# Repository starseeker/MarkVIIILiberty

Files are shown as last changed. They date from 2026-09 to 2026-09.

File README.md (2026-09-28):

# Mark VIII Liberty Tank

This repository is a research and reconstruction project devoted to the First World War–era **Mark VIII tank**, commonly called the **Liberty tank** or **International tank**. It is intended to hold historical notes, transcriptions, photographs, drawings, dimensional evidence, and—eventually—CAD models of the vehicle and its components.

The goal is not merely to produce a visually convincing model. Wherever possible, the project will record the source behind each feature, distinguish documented dimensions from estimates, and preserve uncertainty where the surviving evidence does not support a single answer.

Current state:

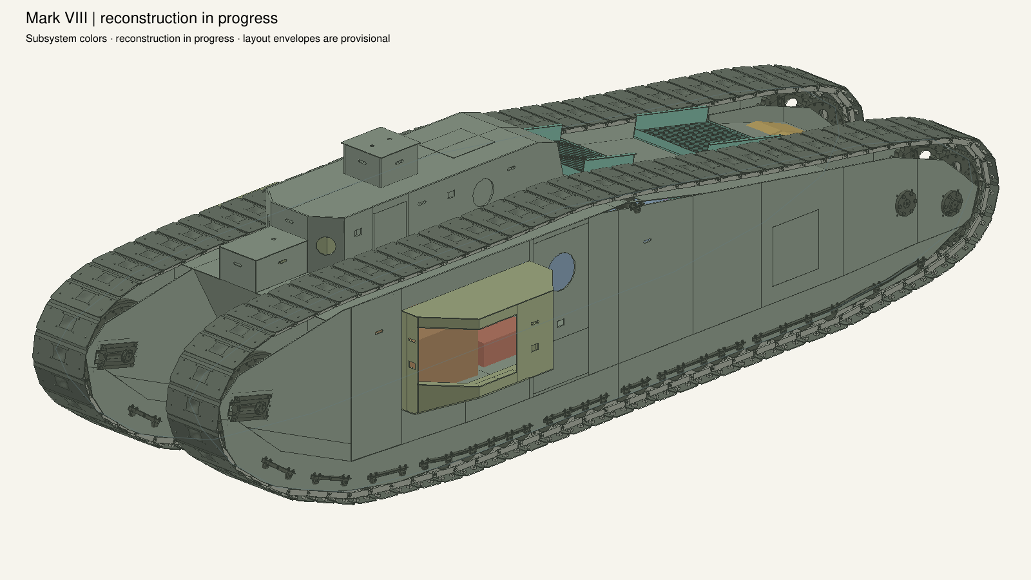
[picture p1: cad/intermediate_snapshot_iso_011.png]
MarkVIII_exterior

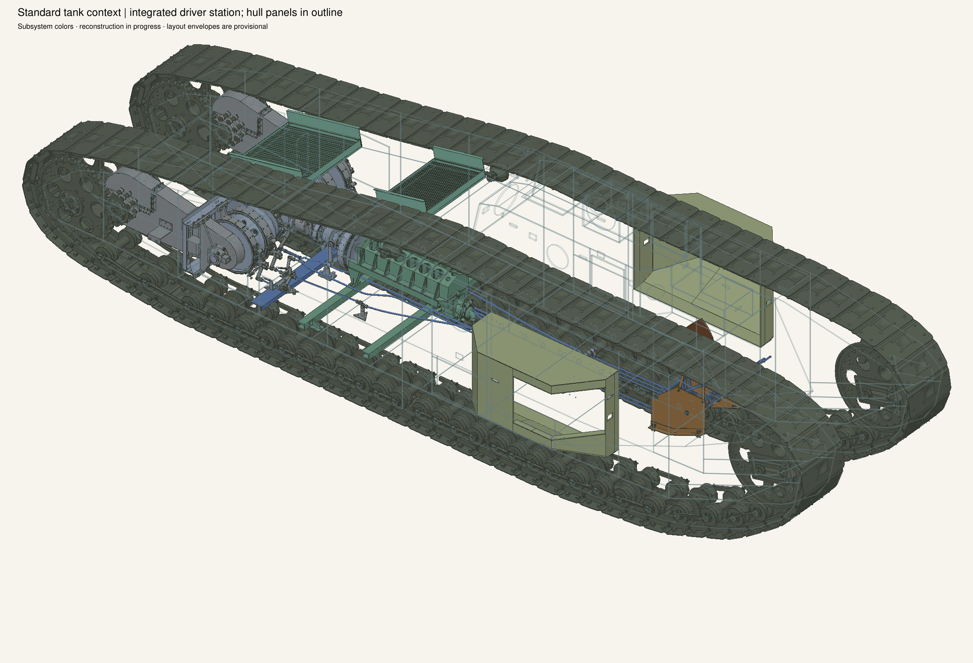
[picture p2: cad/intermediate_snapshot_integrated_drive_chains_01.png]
MarkVIII_interior


## What the Mark VIII was

The Mark VIII was a late-World War I heavy tank designed through a joint British-American program, with France also involved in the intended manufacturing arrangement. The design was meant for the anticipated 1919 Allied offensive and represented an attempt to combine British experience with American industrial capacity. Its collaborative origin is why it is often called the **International** tank.

The American version was powered by a 300-horsepower Liberty L-12 engine, which gave rise to the name **Liberty tank**. It was a large, slow, trench-crossing vehicle with a long hull, substantial track runs, and a separate engine compartment—an important improvement over the cramped engine-and-crew arrangements of earlier British heavy tanks. Its principal armament consisted of two 6-pounder guns mounted in side sponsons, supported by multiple machine guns.

The Armistice came before the tank could enter combat. After the war, the United States assembled 100 Mark VIII tanks at Rock Island Arsenal during 1919–1920 using British-made armor and other components. They served primarily as training vehicles with the U.S. Tank Corps and later the Infantry Branch until their retirement in 1932. British production and prototype counts are reported somewhat differently depending on whether a source is counting national variants, prototypes, or completed vehicles; this repository will preserve those distinctions rather than silently collapsing them into one number.

Only three Mark VIII tanks are generally reported to survive: one British-built example at [The Tank Museum](https://tankmuseum.org/tank_collection/mark-viii?country=all&era=all&tname=&tpage=), and two American examples in U.S. Army collections, including the restored vehicle at [Rock Island Arsenal](https://www.aschq.army.mil/About/History/Tours/RIA/Ordnance/) and the example described by the U.S. Army’s [Mark VIII historical article](https://www.lineofdeparture.army.mil/Journals/Army-History/Archive/Summer-2024-Issue/MarkVIII/). Contemporary testing is also documented in the Imperial War Museums’ film record, [“Trials of the Mark VIII ‘Liberty’ tank”](https://film.iwmcollections.org.uk/record/4178).

## Research and modeling scope

The project may include:

- historical background and terminology;
- source and archive references;
- scans, photographs, and extracted technical drawings;
- transcribed dimensions and dimensional comparisons;
- notes on American and British production differences;
- FreeCAD or other open CAD source files;
- scripts for image preparation, measurement, and model generation; and
- rendered views and documentation of the completed models.

The intended modeling standard is **evidence-led reconstruction**. A part may be modeled as confirmed, probable, inferred, or purely illustrative, with the status recorded in the accompanying documentation. When multiple surviving tanks or drawings differ, the model should identify which configuration it represents instead of presenting one vehicle as universally definitive.

The current source strategy separates the intended 1918 design, later American production and service practice, component-specific documentation, and modern observation. The [primary-source index](docs/primary-sources.md) now includes the 1920 Rock Island Arsenal production account, contemporary Ordnance technical articles, official 1920 reports, a participant's account of the International-tank program, Alden's sponson patent, and period test films. The [modern-reference index](docs/modern-reference-sources.md) remains separate so that observations of surviving museum vehicles are not confused with period design evidence.

The adopted first CAD baseline is the 1919–1920 American Rock Island first-100 production tank. The 1918 prototype or British/International configuration and later service states represented by the 1928 SNL may differ in fittings, equipment, and details. Those differences should be represented as documented variants rather than silently merged.

## Possible repository layout

The structure will evolve as the project develops, but a likely arrangement is:

```text
docs/          historical notes, source summaries, and research log
references/    photographs, drawings, dimensional references, and indexes
cad/           FreeCAD documents and other native model files
exports/       selected meshes, technical illustrations, and renderings
scripts/       processing and model-generation utilities
```

Large or externally hosted source files may be represented by metadata, checksums, accession information, and links rather than committed directly. Copyright, archive terms, and provenance should be recorded whenever material is added.

## Historical references

- [Primary sources and modeling hierarchy](docs/primary-sources.md)
- [Modern observational sources](docs/modern-reference-sources.md)
- [The Mark VIII Tank — U.S. Army, *Army History*](https://www.lineofdeparture.army.mil/Journals/Army-History/Archive/Summer-2024-Issue/MarkVIII/)
- [Mark VIII Tank — Rock Island Arsenal](https://www.aschq.army.mil/About/History/Tours/RIA/Ordnance/)
- [Mark VIII — The Tank Museum](https://tankmuseum.org/tank_collection/mark-viii?country=all&era=all&tname=&tpage=)
- [Tank Mark VIII — Imperial War Museums film collection](https://film.iwmcollections.org.uk/record/4178)

## Status

The [CAD foundation and pilot](cad/002_Foundation/README.md) provides a scripted
FreeCAD build of representative track, roller, and structural-joint parts in a
hierarchical assembly, with a simplified vehicle reference blockout. It includes
source-linked parameters, calibration records, STEP exports, and validation.
The [source survey](cad/001_Survey/survey_report.md) remains the frozen research
baseline. Geometry with incomplete historical evidence is explicitly provisional;
the pilot is not a complete or manufacturing-ready tank model.

The [complete-tank workflow](docs/complete-tank-workflow.md) defines the path from
that pilot through production inventory, full-vehicle layout, exterior and
interior reconstruction, and a validated native assembly release. Its
[execution queue](cad/003_FullTank/README.md) records the work packets and
dependencies. Full-tank implementation now includes a production-triage inventory,
an initial native installation layout, seven track component definitions in two
closed 78-unit tracks, 26 individual upper enclosure plates and closed leaves,
77 main hull plates, 39 sponson plates, 82 roof-louver components, 1,228 components
in 60 lower/upper roller stacks with four upper support angles, 306 front-idler
wheel/shaft/adjustment components, 34 lower support angles with 76 attachment
bolts, 298 driving-wheel/shaft/bearing components, 196 partial roller-pinion
components, and source/model comparison views. The
upper enclosures, hull and sponsons now have hollow interiors, with separate
floors, sides, roof pieces and closed standard leaves. Remaining hull structures,
sponson shields/supports, lower support retention, upper attachment/covers,
exact drive/pinion bearing profiles, chain drive and remaining idler attachment details,
louver spacing/support hardware, fittings and interiors still need population. The
[visual progression](cad/VISUAL_PROGRESSION.md) preserves milestone isometrics,
including a transparent-hull view from milestone011 onward. The isolated
[transmission bevel-drive candidate](cad/003_FullTank/packets/I03-bevel-drive.md)
now contains 1,199 parts, including bevel gears, clutch and thrust-bearing
internals; standard-tank integration is pending.
Track closure uses the
printed pin pitch; wheel engagement remains unresolved. The complete tank and
interior reconstruction remain in progress. Standard assembled geometry takes
priority; selected static poses follow after that population work.

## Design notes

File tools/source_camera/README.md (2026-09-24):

# Reusable source cameras

Each source image has an explicit projection hypothesis, fitting landmarks,
independent held-out landmarks and an immutable numerical fit. New geometry is
normally viewed through the existing camera. A lower residual alone does not
justify changing it or changing the CAD model.

The fitter supports perspective (square pixels, no lens distortion), orthographic
(including rotated axonometric views) and explicitly selected oblique/affine
illustrations. Affine projection is not a physical perspective camera. Mixed
views, exploded arrangements and local drawing distortions may have no single
valid camera. Classify these instead of increasing model flexibility until they fit.

## Reuse and refit policy

| Change | Action |
|---|---|
| New unrelated parts, detail, color or visibility | Reuse camera; render current geometry |
| New held-out landmarks | Reuse camera; recompute residuals |
| Holdouts conflict | Flag review; inspect picks, projection and geometry independently |
| Fitting anchor placement changes | Recompute coordinates; review refit reason; retain old fit |
| Anchor definition changes | Stop and reverify the local locator against the revised shape |
| Source pixels/crop/rotation change | Reverify image picks; use a new image hash |
| Projection, assumptions or solver changes | Separate fit version and before/after review |

Numerical fits are usually inexpensive on small landmark sets. Source reading,
landmark identification and diagnosis are the costly reasoning steps worth
preserving. Cache identity includes original image bytes and dimensions, projection,
fit coordinates/picks/uncertainties, assumptions, fitter code and numerical library
versions. It excludes unrelated geometry and holdouts. Every reuse reassesses the
current holdouts. Camera changes never mutate CAD geometry.

### When to reverify

Reverification and refitting are separate decisions. Reuse the saved camera for
routine detail additions. When producing a source comparison, resolve the current
CAD anchors and reassess holdouts before interpreting the overlay. Review the
projection hypothesis again when a newly populated subassembly supplies useful
depth information, a previously estimated anchor gains better dimensional
evidence, or a new source contradicts the existing interpretation. These events
call for targeted checks, not an automatic new fit or a reread of every figure.
Preserve the source classification, landmark identities, uncertainty rationale
and unresolved ambiguities alongside the numerical camera.

Inspect where discrepancies occur. A disagreement confined to one uncertain
component first calls for checking that component and its image picks. A coherent
pattern across several independently supported parts is a reason to investigate
camera/projection or scan assumptions. Neither pattern proves its cause; mixed
illustrations and local scan distortion may not admit a single camera. Add useful
new features as holdouts first, retaining the existing fitting/checking roles.

Before adopting a refit, record the evidence that warrants revising the old hypothesis
and compare both cameras against the same current geometry and independent check
features. Preserve the previous assessments as well. A smaller fitting error is
insufficient if it merely compensates for estimated geometry or worsens agreement
with established parts. Revisit only the affected source views; standard
progression cameras remain fixed. Routine evidence review belongs to the modeling
workflow and does not require another user approval.

A packet needs `source_image`, `source_sha256`, `image_size_px: [width,height]`,
`projection`, and `landmarks`. Each landmark has a unique `id`, `use: fit|holdout`,
`world_mm: [x,y,z]`, `pixel: [u,v]`, and positive `sigma_px`. Use original decoded
pixels, x right/y down; no implicit EXIF rotation. Uncertainty must account for
picking and estimated CAD anchors and must be justified before inspecting residuals.
At least eight distributed, nonplanar fitting points and three separate holdouts
are required for a useful review. Planar-only automatic calibration is deliberately
rejected; it needs independent view/intrinsic constraints not implemented here.

For saved CAD, add `native_file`, `manifest` (the existing extraction format) and
an `anchor` on each landmark: `occurrence`, `local_mm`, `definition_sha256`, and
`evidence`. Anchor coordinates are recomputed from actual assembly frames. The
resolver independently checks selected archive BReps and composed placements
against the FCStd, and refuses changed definitions until the locator is reviewed.
Bounding-box points in the controlled demo are synthetic landmarks; they are not
valid substitutes for identifiable points in a historical photograph.

Optional rendering requires `render_occurrences`, optional `render_colors`, and
`tessellation_mm`. Use absolute command arguments with the headless launcher,
which changes the working directory. Paths *inside packets* are repository-relative
or absolute. Example (replace packet/output paths with a prepared review packet):

```sh
python3 tools/source_camera/review.py /absolute/packet.json --cache /absolute/cameras --output /absolute/new_assessment
python3 skills/freecad-reconstruction/scripts/freecad_headless.py --workdir .work/camera-runtime tools/source_camera/review.py /absolute/packet.json --cache /absolute/cameras --output /absolute/new_render --render
python3 tools/source_camera/test_camera.py
```

Every assessment directory is new. Keep its `assessment.json`, `next_packet.json`,
optional geometry/overlay PNGs, and referenced immutable fit. Start subsequent
reviews from `next_packet.json`; it carries `previous_fit_key`. A changed fit with
a prior key requires `refit_review: {reason, reviewer}`. The project reviewer can
make routine evidence-backed decisions; this is not an extra user approval gate.
Keep competing families and before/after residuals, including rejected versions.
`camera_assumptions` records reasoning; it does not implement additional solver
constraints. Current optimization settings are fixed in the versioned fitter.

Overlay circles mark picks, crosses mark projected positions; blue points fit,
magenta points are held out. Solid pixels are blended into the original image.
No automatic framing, image warp or fitted per-part transforms are applied.
Perspective raster depth is reciprocal camera distance; geometry crossing the
near plane fails explicitly. Affine occlusion uses a documented cross-product
view convention and needs visual review. These display meshes do not replace
native solid, interface or STEP validation.

Numerical residual thresholds and conditioning diagnostics **never automatically
accept a historical camera or qualify geometry**. A consistent result still needs
review of anchor identity, spatial distribution, family plausibility and independent
features. Estimated or wrong geometry can produce an apparently good fit.

The constrained robust solver uses SciPy's documented
[least_squares](https://docs.scipy.org/doc/scipy/reference/generated/scipy.optimize.least_squares.html).
The headless renderer consumes FreeCAD BReps directly. GUI/Coin camera export is
not yet implemented; a cropped image's off-centre principal point needs more than
setting a symmetric field of view. Coin's
[camera documentation](https://www.coin3d.org/coin/classSoPerspectiveCamera.html)
is the reference for future GUI parity work.

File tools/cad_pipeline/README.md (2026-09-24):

# Deterministic CAD development pipeline

Run existing builders and independent validators as a declared sequence. This
runner invokes no model and never promotes a candidate. Source interpretation,
visual review, approximation disposition and final integration remain explicit.
It shares orchestration helpers with `tools/cad_packets`, not builder geometry
with independent checkers; existing model-routing benchmarks are unchanged.

From the repository root:

```sh
python3 tools/cad_pipeline/pipeline.py run tools/cad_pipeline/plans/brake_stop_replay.json --id brake_stop_pipeline01
python3 tools/cad_pipeline/pipeline.py status brake_stop_pipeline01
python3 tools/cad_pipeline/pipeline.py verify brake_stop_pipeline01
python3 tools/cad_pipeline/test_pipeline.py
```

Use a fresh ID for changed native builder inputs. Repeating an unchanged run
reuses passed stages only if their inputs, code, runtime, outputs and declared
receipt assertions still match. A changed reentrant checker reruns with prior
outputs preserved. An altered/unfinished immutable builder refuses reuse and
requires a fresh ID; there is no automatic adoption of untracked outputs.

`status` checks the actual worker lock and summarizes saved results. It does not
revalidate evidence. `verify` hashes current dependencies/outputs and checks
receipts without running CAD. Its runtime audit covers declared binary hashes,
resolved aliases and the host Python version; it does not re-execute the stored
numerical-package version probe. `run` re-probes that actual headless stack before
any reuse, so use it after package/system updates. Do not restart a live worker after a controller
interruption: its inherited kernel lock prevents duplicate work. Once that lock
is released, a missing terminal receipt remains unfinished, not a pass.

## Plan contract

Version 1 plans use `mode: local_development`, a stable plan `id`, and ordered
`stages` with `id`, `needs`, argv `command`, `inputs`, `outputs`, `reentrant`, and
`timeout_seconds`. Paths support `{root}`, `{run}`, `{python}`. Outputs stay within
the run directory. Inputs and outputs must be regular files, not symlinks/hardlinks.
Runtime aliases such as snap `current` are resolved and their targets hashed.

`python_sources` plus plan `python_paths` identify the static local import closure.
**Audit dynamic imports, data files, BRep references, external helpers, numerical
settings and environment variables explicitly.** AST discovery cannot establish
all dependencies. Broad dependencies may cause extra reruns; missing dependencies
can cause incorrect reuse. The brake-stop replay manifest is an audited example,
not a generic automatic dependency detector. Avoid globbing unrelated generations.

Bind independent checker receipts to both a true success flag and the candidate
native hash. JSON-pointer checks distinguish `true` from `1`. Zero process exit
alone is insufficient where a checker supplies a structured result. The runner
rechecks declared inputs after execution and rejects changes during a stage.
Plans are loaded once at invocation start; edits take effect on the next run.

Records, full logs, attempts and invocation metrics live under
`.work/cad-pipeline/<id>/records`. `state.json` is the compact recovery pointer;
`latest.json` per stage points to evidence. Preserve these with promoted review
bundles; `.work` alone is not a final deliverable. Hash checks protect accidental
staleness, not an adversary who rewrites code and all records together.

## Cost and routing

Metrics count executions, reuse, failure and recorded stage execution time.
Previously spent execution time is a useful workload measure, **not a measured
end-to-end speedup**: hashing, runtime probes and orchestration still take time.
The runner's model invocation count is zero; the supervising assistant's token
usage is **unmeasured**, not zero. Include failed runs and review/repair work in
future acceptance-cost comparisons. Continue using the conservative reviewed
packet routing in `tools/cad_packets`; do not reduce reasoning effort for new
mechanisms, source conflicts, spatial interpretation or acceptance decisions.

## Deliberate limits

Plans are trusted project code, not a security sandbox. Dependencies on current
placements/neighbors must be declared for context checks. Definition-only results
do not qualify installation. The current replay covers local brake-stop checks,
rebuild and parameter variation, but it does not accept historical part aliases,
verify complete service paths, reconcile the tank inventory or release the full
standard assembly. Final integration checks remain required.

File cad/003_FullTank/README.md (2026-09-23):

# Complete-tank workflow and execution queue

This stage contains the **full-tank installation layout, closed track loops and
individual upper/main hull plates, hollow sponson plate shells, roof louvers and
lower/upper roller stacks, upper/lower support angles, partial front idler wheels/adjusters and driving wheels with partial shafts/bearings and roller pinions**. The complete
tank remains in progress.
Follow the [complete-tank workflow](../../docs/complete-tank-workflow.md).
The working target is the Rock Island first-100 production configuration, all
identifiable installed components including interiors, documented approximations,
and selected static poses. The user confirmed the interior and pose scope on
19 September 2026.

The current priority is to fully populate the standard assembled configuration,
including identifiable interiors. Pose variants follow that geometry work.
Preserve significant standard-view milestones as numbered
`../intermediate_snapshot_iso_NNN.png` images and update the
[visual progression](../VISUAL_PROGRESSION.md); keep existing snapshots intact.

`work_queue.json` is the dependency-ordered work inventory. Packet statuses record
actual progress; acceptance criteria describe the complete required result.
The validated foundation remains in
[`../002_Foundation/`](../002_Foundation/README.md).

When starting a packet, copy the
[work-packet template](../../docs/templates/cad-work-packet.md) to `packets/<ID>.md`.
Keep evidence records and geometric outputs tied to those packet IDs. The queue
is a scheduling aid; it does not replace the eventual configuration-specific
component inventory, occurrence BOM or parameter registry.

## Run and inspect

From the repository root:

```sh
python3 cad/003_FullTank/manage.py inventory
python3 cad/003_FullTank/manage.py check
python3 cad/003_FullTank/manage.py build
python3 cad/003_FullTank/manage.py validate
```

Open **build/native/MarkVIII.FCStd** in FreeCAD. Keep its library and subsystem
directories with it. The standard assembly contains 11 layout definitions,
seven track definitions, 26 upper plate/leaf definitions and 77 main hull plate
definitions, plus 39 sponson plate, 19 louver, 14 roller, ten wheel, eleven idler-mount, ten drive-mount, ten pinion and eighteen lower-support definitions. Its 5,341 leaves comprise 15 layout
occurrences (13 solids and two wires), 2,964 components in two 78-unit tracks,
103 upper/main hull plates, 39 sponson plates, 82 louver components and 1,228
components in 60 roller stacks (58 lower and two separate handbook upper, including four M2092 angles), plus 306 idler wheel, shaft and adjustment components, 110 lower support/bolt components 298 driving-wheel/shaft/bearing components and 196 pinion/shaft/mount components.
Each shoe unit has the 19 physical leaves specified by the SNL. Upper and main
hull plates cover 84 source identities, with hollow enclosures, floors, open
sponson/louver apertures and closed standard leaves. All physical definitions
retain partial coverage. Exact drive shaft/bearing and tensioner profiles and inner plate retention, continuous drive/idler engagement, exact lower support sections and removable retention, upper attachment and covers, remaining hull structures/fittings,
sponson shields/supports/fittings, louver spacing/support hardware and interiors remain open; no complete tank is claimed.

Open **build/comparisons/index.html** for source/model comparisons. The SNL
longitudinal overlay projects actual native edges through the fixed recorded
calibration; its opacity slider exposes differences. The independently retained
handbook cutaway appears beside a model view. No automatic fit is applied to make
either comparison agree. Source-traced profiles are explicitly distinguished from
independent dimensional or visual checks. Shaded views use software rendering;
native CAD and STEP remain BRep geometry. Track close-ups compare the actual
three-unit reconstruction with HB Plate 84. Shading and visible native edges
distinguish the shoe, paired link bars and connecting hardware. Whole-vehicle
previews omit small track hardware for legibility; close views, native documents
and physical STEP exports retain it. Upper close-ups compare front/rear plate
assemblies with SNL7 and HB30, with an underside view confirming hollow shells.
Main hull views compare oblique and opposite-side native projections with
SNL7/1, plus an underside inspection. See [S01](packets/S01.md) and
[H01](packets/H01.md) for source conflicts and geometric approximations.
Sponson close views show both handed shells, their hollow interiors and lower
plates; see [the sponson packet](packets/S01-sponsons.md). Louver oblique/top and
blade-section views accompany SNL4; see [the louver packet](packets/X01-louvers.md)
for conflicting counts and section assumptions. Roller oblique and transverse
section views accompany HB88/89 and SNL29. The [upper support packet](packets/R02-upper-supports.md) records the corrected pin/angle interface and unfinished attachment. See [R02](packets/R02.md) for the
separate quantity scopes, dimensional conflicts and reported source-station
offsets. The upper roller position follows the rear roof bend and HB144's
engine-room access description. The [idler-wheel packet](packets/R02-idler-wheels.md) records the separate rims, disks, boss, diaphragms, rivets and bushes, including the coupled foremost-roller clearance correction. The [mounting packet](packets/R02-idler-mounts.md) covers the two source-complete shaft BOMs and partial adjustment installations. Source comparisons include elevation, transverse section, mounting detail and adjustment-axis section views. Earlier visual milestones remain in the
[visual progression](../VISUAL_PROGRESSION.md); the latest mounting milestone is
[snapshot011](../intermediate_snapshot_iso_011.png), with preserved
[pinion and wheel](../intermediate_snapshot_detail_pinions_011.png) and
[pinion shaft/support](../intermediate_snapshot_detail_pinion_mounts_011.png) close-ups.
A [transparent-hull isometric](../intermediate_snapshot_iso_transparent_011.png)
exposes the enclosed components; its armor uses 18% display opacity. The colored
interior layout envelopes remain provisional. The
[pinion packet](packets/R02-roller-pinions.md) records the source counts, static
clearances, inferred fuel-backplate station and unresolved tooth-count conflict.
The [drive-wheel packet](packets/R02-drive-wheels.md) records the source tooth-count
conflict, shared wheel geometry and corrected rim alignment. The
[drive-mount packet](packets/R02-drive-mounts.md) records the completed source shaft
BOMs, corrected receiving-plate identities and partial bearing interfaces.
The [installed support close-up](../intermediate_snapshot_detail_supports_008.png)
remains preserved from snapshot 008.
The [lower-support packet](packets/R02-lower-supports.md) records source allocations,
front skirt refinement, native bearing/receiver checks and unfinished retention.

The latest isolated [transmission candidate](experiments/drive_chains/transmission_case_mount_trial_build/MX5CaseMountTrial.FCStd)
contains **1,407 valid solids**, including both planetary trains, bevel drive,
input installation, brake-bearing supports, case joint, reversing controls and
four MX5 case attachments. The [mounting packet](packets/I03-case-mount-trial.md)
accepts the long receiver bosses as a documented casting approximation; their
visible source-profile discrepancy remains explicit. The trial filename and
original receipts are preserved; subsequent `qualification.json` records this
acceptance. All 183 affected material pairs, 61 interfaces, 84 independent checks,
19 STEP comparisons and three local variants pass.
The preceding [vertical-controls packet](packets/I03-vertical-controls.md)
retains the 1,391-solid checkpoint with its shaft,
keyed levers, two bearings and distinct MX11/MX12 attachments. All 148 affected
material pairs, 21 native/STEP comparisons, 116 independent checks and three
parameter trials pass; 63 interfaces are rechecked and 641 retained. Seven
inspected views record the remaining source-contour differences. Three new
snapshots show the [installed rear](../intermediate_snapshot_iso_transmission_vertical_001.png),
[mechanism](../intermediate_snapshot_iso_transmission_vertical_mechanism_001.png)
and [bearing/key section](../intermediate_snapshot_detail_vertical_bearing_001.png).
No. C key dimensions and blind bearing construction remain inferred. The
[air-pressure pump](packets/I05-air-pressure-pump.md), separate input-bearing
support, brakes, oil circuits, long controls and standard tank
integration remain ahead. Standard tank 011 and its transparent companion are unchanged.
The existing M249 quantity, MX25 count/nut and MX14 length conflicts remain open
in the preceding packets.

The separate [air-pressure pump native assembly](experiments/drive_chains/air_pressure_pump_build/AirPressurePump.FCStd)
adds 51 source-linked physical pieces, including four pistons and return springs,
a cam shaft, bushes and pulley. Its [assembled STEP](experiments/drive_chains/air_pressure_pump_build/AirPressurePump.step),
[isometric](../intermediate_snapshot_iso_air_pressure_pump_001.png) and
[internal view](../intermediate_snapshot_iso_air_pressure_pump_internals_001.png)
are available for inspection. All 139 local material pairs, 104 independent checks,
17 detailed STEP comparisons, 51 placed-solid exchange checks and two dimension
trials pass. The [pump packet](packets/I05-air-pressure-pump.md) records scale and
hidden-detail approximations. This core is not yet part of the standard tank011 assembly.

The subsequent [pump mounting reconstruction](experiments/drive_chains/air_pump_mount_build/TransmissionWithAirPump.FCStd)
combines that pump with the transmission and adds 32 bracket/stud/fastener pieces,
including the twelve base-attachment pieces. Its 1,490 physical leaves retain
separate FuelPressure and Drivetrain ownership. The
[installation STEP](experiments/drive_chains/air_pump_mount_build/AirPumpInstallation.step)
exports the 83 additions and two revised receiving castings. Pump height, bracket
shape and MX99 construction remain explicit hypotheses, with
[handbook comparison](experiments/drive_chains/air_pump_mount_build/source_review/source_comparison.png)
and a conditional 54-inch belt study. Clutch-stop drive geometry, air lines and
standard-tank integration remain unfinished at that checkpoint.

The [clutch-stop drive candidate](experiments/drive_chains/clutch_drive_build/TransmissionWithClutchDrive.FCStd)
extends the combined model to **1,520 physical components**. It adds the coupling
box, two cover halves, stop drum, shaft, eight bolt/nut/washer sets and a closed
V-belt representation. The belt fit moves the pump and its supports together.
[HB/SNL comparison](experiments/drive_chains/clutch_drive_build/source_review/index.html)
led to a wider shaft head; its transverse form and the handbook-to-catalogue
shaft dimension transfer remain uncertain. The [packet](packets/I03-clutch-stop-drive.md)
records scope, approximations and checks. The full clutch, air circuit and standard
tank integration remain unfinished.

The [front-clutch checkpoint](experiments/drive_chains/front_clutch_build/TransmissionWithFrontClutch.FCStd)
extends the combined native to **1,530 physical components** with a front
coupling, split spring flange, seven-turn NURBS spring and two fastening sets.
It also blends the cardan shoulders and relieves the adjacent receiving passage.
All 88 material pairs, 70 independent checks, 8 definition STEP comparisons,
12 placed-solid exchange checks and two size trials pass. The
[source comparison](experiments/drive_chains/front_clutch_build/source_review/index.html)
and [packet](packets/I03-front-clutch.md) retain the coupling identity transfer,
spring diameter convention and catalogue bolt-callout mismatch. The
[isometric](../intermediate_snapshot_iso_front_clutch_001.png) shows the installed
spring and coupling; the main collar, cones, bearings and standard integration
remain unfinished.

The subsequent [collar-joint checkpoint](experiments/drive_chains/clutch_collar_build/TransmissionWithClutchCollar.FCStd)
contains **1,540 physical components**. Closer SNL inspection required separate
spring and collar flanges and a forward end-bearing pocket; the earlier coupling
approximation remains preserved. The new collar, ring, bush, six drilled screws
and continuous locking wire complete this joint. All 104 independent checks,
65 local interference pairs, 8 definition STEP comparisons, 20 placed-solid
exchange checks and two size trials pass. The [source comparison](experiments/drive_chains/clutch_collar_build/source_review/index.html)
shows the corrected and earlier sections, and the [packet](packets/I03-clutch-collar.md)
records estimated stations, bearing fits and wire geometry. The
[isometric](../intermediate_snapshot_iso_clutch_collar_001.png) preserves this
stage. Main internal clutch parts, cones, operating connections and standard
integration remain unfinished; tank 011 retains its transparent hull companion.

The [main-clutch core](experiments/drive_chains/clutch_stack_build/TransmissionWithClutchStack.FCStd)
now contains **1,549 physical components**: a relieved bearing, nested sleeve,
four keys, cone support, thrust collar and separate external snap ring extend
the 1,540-component parent. Full SNL callout tracing corrected the first core's
end-ring mapping; its rejected native and images remain preserved. The
[source comparison](experiments/drive_chains/clutch_stack_build/source_review/index.html)
shows the full plate and both sections. The [packet](packets/I03-clutch-stack.md)
records the correction, HB/SNL dimensional transfers and thicker key bands from
the literal handbook interpretation. Ball reaction, cones, spring plungers,
exact drive attachment and engine engagement remain unfinished; standard tank
integration follows.

The next [clutch thrust checkpoint](experiments/drive_chains/clutch_thrust_build/TransmissionWithClutchThrust.FCStd)
contains **1,581 physical components**, adding a separate SH998C retainer,
30 quarter-inch balls sharing one definition, and the SH998A spring-stop ring.
The existing thrust collar now has a receiving race; all other 1,548 parent
occurrences retain their geometry and placement. All 95 affected material pairs,
460 independent checks, four definition STEP comparisons, 33 placed-solid checks,
two coupled size trials and a fresh rebuild pass. Seven fine native/source views
were inspected. The [packet](packets/I03-clutch-thrust.md) records estimated race,
cage and ring geometry, the contact-query diagnostic and unfinished plunger/cone
interfaces. The [source comparison](experiments/drive_chains/clutch_thrust_build/source_review/index.html)
retains the full SNL figure. Standard tank011 remains unchanged.

The [cone and spring checkpoint](experiments/drive_chains/clutch_cone_build/TransmissionWithClutchCone.FCStd)
contains **1,652 physical components**. It adds 71 occurrences across nine shared
part definitions and refines the existing cone support; 1,580 parent components
retain their geometry and placement. All 326 affected material pairs, 462
independent checks, ten definition and 72 installed STEP comparisons pass, along
with two coupled dimension trials and a fresh rebuild. Seven native/source views
were inspected, and four new progression snapshots are preserved.

The [packet](packets/I03-clutch-cone.md) records conditional handbook dimensions,
conflicting spring free lengths and estimated receiving profiles. Independent
hole checks caught two bad Boolean cuts despite passing whole-part interference
and STEP tests; the corrected cutters and retained diagnostics are included.
The [source review](experiments/drive_chains/clutch_cone_build/source_review/index.html)
shows the full SNL figure beside actual native sections. SH861K plunger locking
wire/head holes were unfinished at that checkpoint.

The [plunger retention checkpoint](experiments/drive_chains/clutch_retention_build/TransmissionWithClutchRetention.FCStd)
contains **1,653 physical components**: one new SH861K wire, six revised plunger
heads sharing one definition, and 1,646 preserved parent occurrences. The wire
retains the catalogue 30in length; diameter, head passages and route are documented
estimates. All 84 independent checks, 68 material pairs, nine STEP comparisons,
two parameter trials and a fresh rebuild pass. Five views were inspected and
three new progression snapshots are saved. The [packet](packets/I03-clutch-retention.md)
records these checks and the numerical volume diagnostic.

The latest [engine driving-gear candidate](experiments/drive_chains/engine_gear_build/DrivetrainWithEngineGear.FCStd)
contains **2,153 physical components**: 22 new, two locally revised and 2,129
preserved parent occurrences. The main bevel has 33 spline-flanked teeth, an
integral estimated starting claw and splined hub, six complete bolt sets and one
provisional thin shim. The thrust nut has a radial lock screw and formed wire.
Nominal **93 independent checks, 428 affected material pairs including standard
context, and 33 native/STEP comparisons pass**. A coupled module/face/web trial
passes 93/428/33, including STEP. Six native views were inspected;
three new images bring the progression to 129. The [packet](packets/P01-engine-driving-gear.md)
retains the handbook bolt-grip conflict and unverified hub/locking details.
Mating gears, final backlash/shims/timing and the remaining engine systems are
pending. Combined qualification and standard integration remain open.

The [shaft-closure development candidate](experiments/drive_chains/engine_shaft_fittings_build/DrivetrainWithEngineShaftFittings.FCStd)
contains **2,131 physical components**: 139 new plugs, gaskets and retaining
constituents, one revised shaft and 1,991 preserved parent pieces. Nominal
**268 independent checks, 738 affected material pairs including standard context,
and 157 STEP comparisons pass**. Six continuous oil-route witnesses pass with
the stud sets installed. A coupled cap/gasket/nose-bore trial passes
268/738; trial STEP remains unchecked. Seven views were inspected;
three snapshots bring the progression to 126. The
[packet](packets/P01-engine-shaft-fittings.md) preserves catalogue conflicts and
inferred cap/nose geometry. Gear, shims, thrust lock and the remaining engine
systems are pending; combined qualification and standard integration remain open.

The [crankshaft development candidate](experiments/drive_chains/engine_crankshaft_build/DrivetrainWithEngineCrankshaft.FCStd)
contains **1,992 physical components**: 81 new constituents, two receiving-case
revisions and 1,909 preserved parent pieces. It adds the hollow six-throw shaft,
seven pairs of main-bearing halves, their dowels, double thrust internals, sleeves,
key and output retention. SNL17 and LIB17 support the selected one long/six short
bearing pairs; printed lengths are 115/49 mm. Unprinted profiles and thrust sizes
remain estimates. Nominal **437 independent checks, 517 affected material
pairs including standard context, and 101 STEP comparisons pass**. A coupled
trial passes 437/517. Eight views were inspected against manual figures;
three snapshots bring the progression to 123. The [packet](packets/P01-engine-crankshaft.md)
records rejected flange/receiver fits, source decisions and remaining shaft/engine
work. Full drivetrain qualification and standard integration remain open.

The [engine-case development candidate](experiments/drive_chains/engine_case_build/DrivetrainWithEngineCase.FCStd)
contains **1,911 physical components**, including two new hollow crankcase
castings. Seven support occurrences change to accommodate the sump; all1,902
unaffected inherited components are preserved. The case has twelve cylinder
receivers, integral bearing webs, a dry gear chamber and lower oil trough/wells.
Nominal191 independent checks,71 affected material pairs including standard
context, and15 STEP comparisons pass. A coupled thicker/deeper casing trial
passes191/71. Eight native views and the fixed source projection were inspected;
three new images bring the progression to120. The [packet](packets/P01-engine-case.md)
documents the rejected first trial, estimated profiles and unresolved engine
registration, bearing identities and mounting count. This is a development
checkpoint; engine internals and combined qualification/integration remain open.

The [engine-suspension development candidate](experiments/drive_chains/engine_suspension_build/DrivetrainWithEngineSuspension.FCStd)
contains **1,909 physical components**: 61 new pieces and two receiving revisions,
preserving 1,846 inherited occurrences. Both longitudinal rails, three suspension
brackets, packings, bevel washers and catalogue hardware populate all 72 SNL242
support children, plus 14 direct floor rivets. Nominal 202 independent checks,
159 affected material pairs and 83 STEP comparisons pass. A coupled parameter
trial passes 202/159, including standard context. Seven native views and the
fixed SNL2 projection were inspected; three new images bring the progression
to 117. The [packet](packets/I01-engine-suspension.md) records estimated profiles,
conditional aviation mounting dimensions, and the unresolved six-versus-seven
engine mount count. Engine case receivers and sump fit remain pending. This is a
development checkpoint; standard tank011 and its transparent view await combined
qualification and integration.

The [engine-crossmember development candidate](experiments/drive_chains/engine_crossmember_build/DrivetrainWithEngineCrossmembers.FCStd)
contains **1,848 physical components**: 25 new frame/rivet pieces, two replacement
floor contexts and one revised floor, preserving 1,820 inherited occurrences.
Both transverse channels, the front cleat, rear gussets and 14 direct floor
rivets are populated. All 151 independent checks, 93 affected material pairs and
40 STEP comparisons pass. A coupled station/span/depth trial also passes 151/93,
including standard context. Six native views and a fixed SNL2 projection were
inspected; three new snapshots bring the progression to 114. The
[packet](packets/I01-engine-crossmembers.md) records source conflicts, estimated
profiles and floor seams, and the remaining suspension/rail interfaces. This is a
development checkpoint; standard tank011 and its transparent-hull view remain
unchanged pending combined drivetrain qualification and integration.

The [clutch-brake development candidate](experiments/drive_chains/clutch_brake_linkage_build/TransmissionWithClutchBrake.FCStd)
contains **1,821 physical components**. Its 35 additions populate the anchor,
mounting hardware, spring-loaded eyebolt, stop rod and bell-crank assembly. Four
receiving parts change; the other 1,782 parent occurrences are preserved. All 112
independent checks, 273 affected material pairs and 64 STEP comparisons pass,
along with a coupled local dimensional trial. Six native views were inspected and
three snapshots bring the progression to 111. The
[packet](packets/I03-clutch-brake-linkage.md) documents the inferred mounting and
linkage arrangement. Engine-frame/engine interfaces, forward controls, source
registration and complete-clutch length remain open. This development checkpoint
awaits combined drivetrain qualification and standard integration.

The preceding [clutch-support development candidate](experiments/drive_chains/clutch_support_build/TransmissionWithClutchSupports.FCStd)
contains **1,786 physical components**. It adds 27 mechanism pieces and a replacement
floor context, revises the main shaft and operating lever, and preserves 1,756
parent occurrences. Both brackets, mounting screws, auxiliary shaft/levers and
rear control rod are populated. Full-source review corrects their longitudinal
direction and removes an unsupported main-shaft hole; the source split pin belongs
to the pending brake bell crank. All 117 independent checks, 88 affected material
pairs and 46 STEP comparisons pass; a coupled dimensional trial also passes local
checks. Five native views were inspected, and three new progression images bring
the total to 108. The [packet](packets/I03-clutch-supports.md) records provisional
floor attachment, unresolved source alignment and clutch length. Full brake,
forward controls and engine-frame interfaces remain required. This candidate is
unqualified; standard tank011 and its transparent-hull view remain unchanged.

The earlier [clutch-stop band development candidate](experiments/drive_chains/clutch_stop_band_build/TransmissionWithClutchStopBand.FCStd)
contains **1,681 physical components**, including the band, lining and seventeen
rivets. The printed stop-drum diameter now controls the coupled belt/pump update.
Geometry, STEP and two parameter trials pass, but the anchor and operating
linkage remain missing. This candidate is unqualified; its
[packet](packets/I03-clutch-stop-brake.md) records the source-envelope questions
to resolve before mounting those parts. Three new progression views bring the
total to 102. Standard tank011 remains unchanged.

The latest qualified [drum/flywheel checkpoint](experiments/drive_chains/clutch_drum_build/TransmissionWithClutchDrum.FCStd)
contains **1,662 physical components**. It adds the outer drum, flywheel, six
drilled screws and their 48in wire. The existing 30in plunger wire now routes
inward to clear the flywheel; the other 1,652 parent occurrences remain unchanged.
All 270 independent checks, 262 interference pairs, 15 STEP comparisons, two
coupled parameter trials and a fresh rebuild pass. Six views were inspected and
four new progression images preserve the visual improvement.

The [packet](packets/I03-clutch-drum.md) records the uncertain hub interpretation,
starter tooth count and flywheel dish profile, including its visible difference
from the handbook sketch. Next are the clutch-stop brake and complete crankshaft,
key/nut retention and starter interfaces. Standard tank011 remains unchanged;
full tank geometry and integration remain incomplete.

Additional commands:

```sh
python3 cad/003_FullTank/manage.py dossier P_a18a32069ef93911
python3 cad/003_FullTank/manage.py build --subsystem Powerplant
python3 cad/003_FullTank/manage.py validate --subsystem Powerplant
python3 cad/003_FullTank/manage.py review
python3 cad/003_FullTank/manage.py export
python3 cad/003_FullTank/tools/transparent_isometric.py
python3 -m unittest discover -s cad/003_FullTank/tests -v
```

Subsystem builds use their own output directory under build. All commands accept
`--output DIRECTORY`. The launcher uses the installed, tested FreeCAD 1.1.1
libraries directly, with its own settings/cache directories; the desktop Snap
launcher does not need to work in the sandbox.
Preview rendering also uses the installed C compiler to build a small software
depth-buffer renderer, cached by its source hash. Repeated definitions reuse a
single tessellation; this does not change the native geometry.

Native features include constrained sketches, pads, revolved cubic B-spline
roller profiles, analytic BRep features and a closed shoe pressing with native
quartic NURBS top/bottom surfaces. Their authoritative
inputs are the records under data and the Python builders. A GUI feature edit can
be inspected, but transfer it back into those inputs before regeneration.
The current layout does not yet provide multiple selectable detail representations,
completed component internals or motion poses. The two static track loops are
closed at every shared pin. Static roller-to-rail clearance is checked; drive/idler
engagement, complete support interfaces and continuous motion remain unqualified.

Validation checks occurrence coverage, actual nested placements against named
datums, shape validity, STEP equivalence, native relocation, an independent
rebuild, unchanged-definition cache reuse, a fuel-tank spacing change and a track
pitch change through nested component placements. Upper checks add independent
SNL plate quantities, handed opening order, nominal material intersections,
hollow interiors, sampled armor thicknesses and a main-width propagation trial.
Main hull checks add source quantities, plate/upper/track material contacts,
lower shell spacing, floor clearance, louver openings and a shell-gap trial.
Sponson checks add independent quantities, handed opening/absence probes, normal
armor thickness, hollow interiors, whole-vehicle width and physical contacts.
A roof-thickness trial verifies inward growth, adjoining wall updates and
unchanged floors. Louver checks add source quantities, exact curved-section
dimensions, open-passage probes, guard projection, physical contacts and a blade
thickness trial. The full pitch trial checks sponson and louver interfaces.
Track checks independently read
the SNL assembly composition and test actual component intersections. Selected
joint-bend trials record limits without claiming a continuous permitted range.
It reports remaining complete-tank gates separately. Reference-envelope overlaps
are not accepted as proof of physical component fit.

The milestone011 qualification retains the original 29-stage/17-parameter-trial
run and 37 record/renderer tests. A fresh main-path check reopened all 20 native
documents and verified every definition, placement and original geometry signature.
The trials were not rerun after this byte-identical geometry transfer. See
[the transfer receipt](releases/011-roller-pinions-transfer.json) and
[release record](releases/011-roller-pinions.json). The original validation
records remain intact under build/reports/qualified_origin.

The inventory includes all 5,482 survey identities, retaining quantity assertions,
variants, issues and review records. Only explicit decisions establish inclusion
or exclusion; the other rows remain production/transfer candidates or unresolved.
The installed vehicle count remains unknown. Generated inventory reports track
which identities have layout or partial component geometry without calling the
vehicle complete. STEP exports separate MarkVIII_Layout.step from
MarkVIII_Components.step.

See [PROGRESS.md](PROGRESS.md) for current findings, remaining gates and the next
implementation work.
The [visual review](VISUAL_REVIEW.md) records inspected artifacts and unresolved
packaging conflicts; [data contracts](DATA_CONTRACTS.md) describe the current
record and placement semantics.

## Implementation organization

The implementation currently uses flat authored JSON records, split into
configuration, parameters, calibrations, datums, definitions and occurrences.
Split these into subsystem directories as their contents grow. The intended
organization is:

```text
cad/003_FullTank/
  README.md
  work_queue.json
  packets/                    evidence, construction and review records
  data/
    configurations/           applicability, quantity scope and selected loadout
    parameters/               typed values, provenance, uncertainty, dependencies
    calibrations/             controls, transforms, residuals and profile traces
    interfaces/               named datums, mounts, axes and ports
    definitions/              geometry builders, identities and representations
    occurrences/              installation hierarchy and local transforms
    poses/                    named static arrangements and supported ranges
    research/                 added sources, reviewed mappings and open issues
  lib/                        reusable evidence, CAD and validation routines
  builders/                   component-family and subsystem generators
  manage.py                   subsystem build/check/export/report entry point
  build/                      generated native, STEP, views, reports and runtime
```

The current command interface and record validation are implemented in manage.py
and lib. Further F02/F03 work adds interface fit contracts and multiple detail
representations. Keep generated files outside authored inputs, and preserve
relative native links in delivery packages. Changes to the frozen survey require
a new research baseline rather than edits here to its published files.

## Queue conventions

- `depends_on` contains packet IDs whose technical outputs must be available.
- `status` records actual work, independently of readiness from dependencies.
- An evidence packet can finish with a bounded documented approximation; it need
  not wait for every archive lead. An unresolved necessary interface keeps the
  affected geometry packet blocked and remains in its issue record.
- Milestone acceptance uses the workflow's gates and all required packets for that
  stage. Later discoveries invalidate affected accepted work and its dependents.
- `accepted_approximate` requires the same geometry/integration checks as
  `accepted`, with its evidence limitations recorded. It does not silently waive
  failed geometry checks or hide unfinished scope.
- The full-tank component count is deliberately unset until F01 and subsequent
  inventory reconciliation establish it.

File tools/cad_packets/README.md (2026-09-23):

# CAD work-packet controller

This controller runs bounded CAD work through Codex CLI and records independent
validation. It currently operates in **shadow mode**: it cannot overwrite the
tank's accepted native documents. The first backend uses the existing CLI login;
there is no API key setup or App Server dependency.

The [tool-enabled trial report](../../benchmarks/cad_work_packets/REPORT.md)
records the initial comparison, timeout diagnostics and separate FreeCAD skill
trial. These results support conservative routing, with review before integration.

## Routing

Medium is experimental and eligible only for `reviewed_implementation` or
`qualified_family` packets with all three reviews explicitly true (dimensions,
sources, interfaces) and no risks. New mechanisms, source conflicts, missing
reviews, interface changes and unknown categories route to xhigh. Failed work
offers a separate xhigh diagnosis. An explicit `--effort` override is recorded
as a shadow comparison, never as permission for automatic integration.

```bash
python3 tools/cad_packets/controller.py route benchmarks/cad_work_packets/packets/stack.json
python3 tools/cad_packets/controller.py run benchmarks/cad_work_packets/packets/stack.json --id my_stack_trial
python3 tools/cad_packets/controller.py status my_stack_trial
```

An identical completed command verifies its inputs and saved evidence, then
reuses the result without inference. Changed inputs, code, CLI version, timeout
or effort require a new run ID. Interrupted runs preserve their records and
workspace; start a new run ID rather than overwriting partial evidence. Workspaces
live in `.work/cad-packets/runs`, while durable requests, outputs, events and
results live in `benchmarks/cad_work_packets/results`.

```bash
python3 tools/cad_packets/controller.py run path/to/packet.json --id repair_diagnosis --diagnose-from failed_run
```

Diagnosis requires the same packet and a failed prior run, copies its declared
artifacts and validation feedback as read-only inputs, and forces xhigh. Its
latency and tokens are recorded separately so failure costs stay visible.

## Packet and validation contract

Use the three JSON examples as executable packet templates alongside the fuller
[CAD work-packet template](../../docs/templates/cad-work-packet.md). A packet needs:

- ID, version 1, `mode: shadow`, category, explicit review flags and risk list.
- Instructions with units, source applicability, dimension assumptions, local
  frames, qualified parents, interfaces, required outputs and unresolved issues.
- Explicit input files: repository-relative source, candidate-relative destination,
  SHA-256. Include full figures and relevant qualified native/STEP/BRep parents.
- Declared files under `deliverables/`; a reviewed validator under `validators/`
  and a passing, current qualification record for that validator.

Validators are authored and qualified before candidate execution. They run in a
separate process and consume saved CAD/data, without importing candidate builders.
Source interpretation and visual comparisons need a separate review: a Boolean
intersection check cannot prove the correct historical part was modeled. Add a
new validator and negative controls when a packet requires new acceptance logic.
The included validator is specific to the three benchmark cases, not a universal
tank-model certifier. Builders also need a reproducibility review before any real
model integration; the current mechanical gate checks their saved outputs.

The project's [FreeCAD reconstruction skill](../../skills/freecad-reconstruction/SKILL.md)
captures tested runtime, placement and evidence-handling guidance. Supply the
skill and relevant resources as hashed packet inputs for isolated workers, as in
`benchmarks/cad_work_packets/packets/stack_with_skill.json`. This makes the intended
guidance readable within the candidate's restricted workspace and records its
revision. Keep the skill/discovery environment fixed during paired comparisons;
the controller records requested CLI settings, not every server-side instruction.

## Isolation and failure handling

The CLI profile grants candidate commands only minimal platform reads, `/snap`
runtime reads, and writes to their own absolute workspace. Packet inputs and the
FreeCAD launcher are read-only. Controller results, validators, other candidates
and production files are outside candidate read/write access. The controller
probes each profile before inference; a hidden sandbox ancestor can accept an
ephemeral write, so the probe also checks the real host canary remains unchanged.
Shell network access is disabled, web search is disabled, and escalation is not
available to candidate commands. The CLI itself still needs its normal saved-login
and runtime access; an outer sandbox may require an approved launch for that.

Independent validation has read access to only its inputs, artifacts and trusted
controller code, and writes to its validation directory. Timeouts terminate the
process group. Missing outputs, malformed events, changed inputs, failed checks,
tampered records and stale validators fail closed. Symlink/hardlink output files
and paths escaping their workspace are rejected. A lock prevents overlapping
controller mutations. Production native CAD hashes are compared before and after.

These are local workflow boundaries, not an adversarial security certification of
FreeCAD or the operating system. Permission profiles are currently a beta Codex
feature; keep the preflight checks when upgrading the CLI. See the official
[permission-profile documentation](https://learn.chatgpt.com/docs/permissions) and
[configuration reference](https://learn.chatgpt.com/docs/config-file/config-reference).

## Review and staging

Passing mechanical checks leaves the run `awaiting_review`. Record actual source
and visual findings with `review`; no automated process calls it on a candidate's
behalf. `benchmark_only` keeps synthetic qualification fixtures out of integration.

```bash
python3 tools/cad_packets/controller.py review RUN_ID --reviewer REVIEWER \
  --disposition benchmark_only \
  --source-note 'Describe the evidence actually checked and remaining assumptions.' \
  --visual-note 'Identify views checked, findings, and any limits to this review.'
```

For real work, `accepted_for_review_bundle` allows `stage RUN_ID` to copy the
reviewed artifacts and provenance into a new, immutable
`cad/003_FullTank/review_bundles/RUN_ID` directory. Staging checks that inputs,
artifacts, review and production parents still match. It never updates the main
assembly or overwrites an existing bundle. Integration into that assembly remains
the established full-tank workflow's separate dependency/visual validation step.

## Checks and extension

```bash
python3 tools/cad_packets/test_controller.py
python3 benchmarks/cad_work_packets/test_review_gate.py
```

CAD qualification runs through `freecad_python.py` in a scratch working directory;
see [the tool-enabled benchmark protocol](../../benchmarks/cad_work_packets/PROTOCOL.md).
The launcher uses installed FreeCAD and Qt snap paths, with settings/cache in that
workspace. `CLIBackend.command()` isolates the execution backend, so a later
App Server implementation can keep packet, routing and acceptance logic intact.

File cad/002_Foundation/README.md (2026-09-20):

# Mark VIII CAD foundation and pilot

This stage turns selected survey evidence into reproducible native FreeCAD parts
and a hierarchical assembly. The baseline is the **1919–1920 Rock Island first-100
production configuration**, with explicitly qualified transfers from the
preliminary handbook and later service illustrations.

The survey remains frozen and read-only. Scripts and `data/*.json` are the
authoritative model; generated files live under the ignored `build/` directory.
There are no required third-party FreeCAD workbenches.

## Build and inspect

From the repository root, run:

```sh
python3 cad/002_Foundation/manage.py check
python3 cad/002_Foundation/manage.py calibrate
python3 cad/002_Foundation/manage.py build
python3 cad/002_Foundation/manage.py validate
```

`build` also runs the environment checks and calibration. `validate` includes
STEP export, previews, relocation, reproducibility, parameter-change tests,
interference checks, and the original 27 survey checks on a disposable copy.
To regenerate exports without the full validation suite:

```sh
python3 cad/002_Foundation/manage.py export
```

Open **`build/native/MarkVIII_Pilot.FCStd`** in FreeCAD. Keep the entire `native/`
directory together when moving the assembly; it uses relative external links.
The generated `build/README.md` links previews and records evidence limitations.
`build/delivery_manifest.json` lists artifact checksums. Generated documents have
native view settings as well as geometry; previews do not require OpenGL.

All commands accept `--output DIRECTORY` and `--data DIRECTORY`. Paths are
resolved independently of the calling directory. Output must be separate from
research inputs. Rebuild after editing either data or Python code before running
validation/export; stale builds are rejected.

## Installed runtime

The launcher uses the tested FreeCAD **1.1.1** libraries in `/snap/freecad/current`
and their Qt runtime in `/snap/kf6-core24/current`. It starts a fresh Python process
with the necessary library paths and redirects application settings/caches under
the output directory. It does not change the ordinary desktop FreeCAD profile or
require the Snap launcher to work inside the agent sandbox.

Alternate installation roots can be supplied with `MARKVIII_FREECAD_ROOT` and
`MARKVIII_QT_ROOT`. A different FreeCAD version must be requalified before changing
the version gate in `workflow.py`. Every check records the exact FreeCAD, Open
CASCADE, and Python-package versions. The native capability probe covers a
constrained sketch, parametric pad, Boolean, NURBS solid and surface, nested links,
and FCStd/STEP round trips.

System Python needs PyMuPDF (`fitz`), Pillow, NumPy, and SciPy; these were available
on the assessed system. FreeCAD's packaged Python must be ABI-compatible with
the interpreter (tested with system Python 3.12). Qt may print an offscreen
OpenGL-widget warning: previews use geometry projection and software rendering.

## Model and evidence interfaces

| Authored data | Purpose |
|---|---|
| `parameters.json` | Millimeter values, original units, reconstruction bounds, evidence, applicability, and derivations |
| `calibrations.json` | Original/derived image paths, crop bounds, independent scale spans, held-out checks, wheel axes, traced profiles |
| `model.json` | Part definitions, survey IDs, native builders, occurrence hierarchy and placements |
| `issues.json` | Named limitations and prioritized research gaps |
| `sources.json` | Hash lock for the frozen survey and consumed sources; bounded supplementary-source inspection notes |

Parameter arithmetic permits numeric literals, parameter names, `+`, `-`, `*`,
`/`, and parentheses only. Derived parameters refer to preceding entries. Bounds
express reconstruction uncertainty or permitted study ranges; they are **not
manufacturing tolerances**. A `blocked` parameter stops the build. Missing sources,
changed locked hashes, unsupported references, invalid values, and missing part
definitions also stop it. Source-lock updates require reviewing the changed
evidence; do not regenerate hashes simply to suppress a failure.

Evidence references use `record:<survey record ID>`, `page:<source>:<printed page>`,
`calibration:<key>`, and `issue:<key>`. Survey `part_id` values are preserved; new
illustrative objects have no invented historical identifier. Occurrences have
stable IDs, parents, configuration, evidence, translation and rotation. Rotation
uses FreeCAD's yaw/pitch/roll convention in degrees; this pilot uses zero rotation.

Coordinates are millimeters, X forward, Y port, Z up. The origin is on the ground
under the rear drive axle at the tank centerline. The configuration is a static
level-ground reference, not a suspension or track-motion solution.

## What the pilot represents

- A recognizable **reference blockout**: hull, upper structures, deployed sponson
  envelopes, track outlines and drive/idler reference rims. These are not armor
  manufacturing parts and are excluded from physical STEP and part counts.
- **Six track shoe/link units**, three per side, using a shared pressed-shoe
  definition and left/right simplified link webs. Shoe width and pin pitch come
  from HB p. 137. Forming details and rail profiles are approximate; pin eyes,
  bushings, pins and rivets are deferred. There is no articulated-track claim.
- **Two five-piece rotating roller units**: two rollers, one tube, and two split
  rings each. Dimensions promoted from HB p. 141 are recorded explicitly.
  Roller waist, bore clearance and groove details remain approximations.
  Shafts, floating bushes, staples and suspension hardware are outside this
  rotating-unit scope. The stored survey assembly ID is retained.
- **One local support-joint coupon** anchored to M2078 (support angle No. 1): a
  straight L section, mating plate and two illustrative unthreaded fasteners.
  This is not the full curved support or a replacement-ready M2078 part.

There are **32 physical solid occurrences** and nine reusable part definitions.
Counts describe this pilot only, not the vehicle BOM. Shared geometry does not
establish historical left/right interchangeability.

The parts use native Sketcher/Part Design pads, revolutions and pockets. Polygon
profiles have explicit blocked geometry; edit those sketch constraints or change
the authoritative data and rebuild. The `Parameters` object retains source
values; shoe-width and plate-thickness pads also have live native expressions.
Other profile parameters require script regeneration. Record useful GUI edits in
the scripts/data before rebuilding, because regeneration replaces native files.

## Calibration and historical limitations

SNL Plates **1, 3, 4 and 10 are perspective photographs**. They are cropped for
visual checks and deliberately receive no global mm/pixel scale. Plate 4's title
does not make it an orthographic plan view.

Plate 2 is a flat-scanned longitudinal section. Its X and Z scales are fitted
independently to the provisional handbook envelope; wheel diameters are withheld
checks. Selected silhouette vertices and wheel centers are recorded in image
pixels. Plate 29 adds the roller section, using its plate-spacing dimension and
the handbook roller diameter on separate axes; roller width and tube length are
withheld checks. The report retains residual disagreements, including those
larger than point-picking uncertainty. Printed part dimensions take precedence
over scaling those particular section details; this does not resolve the wider
source/configuration conflict.

The metric SVG derivatives embed unchanged reference pixels and record separate
horizontal/vertical physical scaling. Overlays show controls and selected
profiles. Original scans, upstream restoration records and hashes remain intact.
No cleaned image is treated as proof of manufacturing precision.

The additional screw-thread report was visually checked at its title and preface;
no thread dimensions are imported because the pilot fasteners are unthreaded and
their historical type is unresolved. Only front leaves of the Lunkenheimer
catalogue were inspected; no exact valve match is claimed, and no valve is needed
for this milestone.

## Verification and next work

Validation checks solid validity, link identities, actual world-space geometry,
contact/overlap, native reopening after relocation, equivalent independent
rebuilds, propagation to all repeated shoes after changing pitch, a plate-thickness
change, and a live native expression update across external links. It exercises
missing-source, blocked-parameter and missing-linked-file diagnostics. STEP
checks use relative volume tolerance `1e-6` and bounding-coordinate tolerance
`1e-5 mm`; these numerical checks do not certify historical dimensions.

Visual review compares the pilot with the retained section and photographs.
Refer to `VISUAL_REVIEW.md` for findings, including differences deliberately left
as provisional. There are no motion joints, complete track loops, manufacturing
drawings, detailed weapons, proprietary machinery internals, or museum-measurement
claims in this milestone.

Next: refine hull plates and sponson interfaces; establish complete running-gear
stations and tracks; then develop engine/transmission installation envelopes and
supported ancillary detail. Keep production fuel tanks/Ball & Ball, Bijur units,
tank-versus-aircraft interfaces, SH642B and missing installation drawings at the
top of the research backlog. Resolve these before treating a whole-vehicle model
as dimensionally complete.

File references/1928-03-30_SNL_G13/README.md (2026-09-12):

# SNL G-13 — Tank, Mk. VIII (1928)

An editable Scribus reconstruction of the U.S. Ordnance Department’s **Standard
Nomenclature List No. G-13, Tank, Mk. VIII**, dated **March 30, 1928**. The work
preserves the book’s printed sequence, table structure and typography as closely
as practicable, while making its text editable and improving the geometry of
photographed illustrations.

**Status:** all supplied pages have been transcribed and assembled. Figure review
and a targeted cross-book ambiguity audit are complete. Independent proofreading
of the entire transcription remains pending. This is a modern research edition,
prepared iteratively with ChatGPT/Codex and user review, rather than an official
corrected edition of the historical publication.

This README summarizes the accompanying `SNL_G13_Project` package. File paths
below are relative to that package’s root. The documented transcription checkpoint
is the audit of **September 12, 2026**.

## Source and archival provenance

The source images come from the Internet Archive item
[Standard Nomenclature List No. G-13 TANK, MK. VIII](https://archive.org/details/SNL_G13_TANK_MKVIII).
Its description identifies the original publication in the **U.S. National
Archives, Record Group 394**, in the series **Ordnance Notes and Handbooks on Guns
and Gun Carriages, 1900–August 1941**, with **National Archives Identifier
26417262**. This is the series identifier, not a separately established identifier
for this individual volume. [Internet Archive item metadata](https://archive.org/metadata/SNL_G13_TANK_MKVIII)
provides the publication and imaging history; the corresponding
[National Archives catalog reference](https://catalog.archives.gov/id/26417262)
is retained for archival lookup.

Additional details were transcribed from the modern archival panel in the supplied
foldout image and are preserved in `data/foldout_provenance.json`:

| Field | Recorded information |
| --- | --- |
| Archival creator | War Department, Office of the Chief of Ordnance, Rock Island Arsenal, Illinois |
| Container | 5 |
| Item | Mark VIII Tank |
| Declassification project | NND 740018 |
| Access and use restrictions shown on the panel | Unrestricted |

The Internet Archive notes explain that the bound pages were photographed with a
camera in **2017**, producing page curvature, perspective distortion and some
local focus problems. The loose foldout facing page 277 was scanned flat on a
large-format scanner. The Internet Archive item was made public in July 2022.
These acquisition differences are preserved in the reconstruction’s treatment of
the images. See the [source item and its imaging notes](https://archive.org/details/SNL_G13_TANK_MKVIII).

The provenance chain is therefore the original National Archives volume, its
photographs and foldout scan, their Internet Archive distribution, and this modern
transcription and layout reconstruction. Original supplied JPEGs remain in
`sources/`; archival cards and modern annotations excluded from the reconstructed
print area are still present in those source images.

## Scope and reading order

The reconstructed book contains **314 electronic pages**: Roman-numbered pages
I–II, Arabic-numbered pages 1–311, and the separate Plate 2 foldout. All **34
plates** are included. There are no missing numbered pages in the supplied set.
The electronic page count should not be interpreted as a count of physical leaves.

| Scribus/PDF position | Original printed label | Contents |
| --- | --- | --- |
| 1–2 | I–II | Front matter and list of plates |
| 3 | 1 | Title leaf |
| 4–278 | 2–276 | 275 parts-table pages |
| 279 | 277 | Plate 1 |
| 280 | Face p. 277 | Plate 2 foldout |
| 281–309 | 278–306 | Plates 3–34 |
| 310–314 | 307–311 | Notes, manufacturer table and use of prices |

The foldout follows page 277 in plate reading order, retaining its “Face p. 277”
reference. Physical binding placement and final printing imposition remain
unconfirmed. Pages 278, 282 and 283 each contain two plates.

`page_inventory.json` and `page_inventory.tsv` map source filenames, original
folios, output positions and source hashes. Repeated uploads were reconciled
without adding duplicate pages. PDF bookmarks and page labels use the original
folios, so references remain usable despite the front matter and inserted foldout.

## Text and Scribus layout

The native document contains **25,682 editable text frames** and **32,632 native
objects**, including text, rules, leaders and artwork frames. The structured
transcription includes **7,571 table records**.

Parts tables were rebuilt with named cell frames and vector rules, preserving the
sideways orientation, column alignment, component indentations, grouped entries,
continuations and source line breaks. They use individual Scribus frames rather
than Scribus table objects. Front matter, headings, notes, page numbers and
printer imprints are also editable. Figures and their internal lettering remain
linked raster artwork.

Main pages use the agreed **6 × 9 inch estimate**. The foldout uses a provisional
**18 × 9 inch** canvas. These dimensions, margins and type sizes have not been
verified by physical measurement.

The bundled **C059 Roman, Bold and Italic** fonts provide a Century-style
approximation. They are not an identification of the original metal type.
Typeset pages use clean text rather than reproducing paper discoloration, tears
or photographic shadows. Fractions, small capitals, dashes, braces and leader
spacing are approximated where necessary. Limited horizontal scaling helps keep
long table cells on their original lines.

Period wording, blank cells and apparent printed inconsistencies are generally
preserved. Supported restorations and uncertain readings are documented in
`review.json`; clearer-looking modern terminology is not substituted silently.

## Figure distortion correction

All **30 numbered figure pages, 277–306**, were reviewed against their sources.
Together with the foldout they produce **31 artwork assets**. Corrections were
chosen according to the evidence available on each page:

- Long printed borders and reference lines constrain perspective and nonlinear
  straightening where they can reasonably be treated as page-aligned lines.
- Captions and selected horizontal or vertical lettering provide additional
  orientation evidence, particularly on unframed plates.
- A survey of the long rules on all 275 table pages supplied 261 accepted page
  models. Nearby observations of the same page parity provide a weak local guide
  to curvature; there is no single universal odd/even transform or assumed flip
  point for the whole book.
- More complex fits were accepted only where supported. Reserved observations
  were used to assess the later refinements, and unsuccessful trials were retained
  in the records rather than applied to the delivered artwork.

The later refinement improved pages **278, 283, 296, 299, 301 and 303**, containing
Plates **3–4, 10–11, 24, 27, 29 and 31**. The largest gains were on pages 283 and
301. Stronger trials on 282, 284 and 294 were rejected; other pages retain their
previous correction or crop. The flat-scanned **Plate 2 foldout was excluded from
book-curvature modeling** and retained its existing crop and placement.

These are restrained geometric corrections of the source pixels. No drawing
linework or lettering was generated. Corrected assets are lossless PNGs; the
original JPEGs remain available. Some interior distortion persists, especially
where reference evidence is sparse. Part silhouettes, intentional perspective and
splayed components were not forced into rectangular or circular templates.

`Figure_Geometry_Proof.pdf` compares source regions with the current artwork.
`Figure_Refinement_Study.pdf` compares the earlier and refined corrections and
records the review of every plate. Methods, controls, rejected trials and numerical
checks are described in `FIGURE_REFINEMENT.md` and `calibration/`.

## Cross-book transcription audit

Once the complete transcription was available, repeated codes, assembly lists,
quantities, end notes and selected original photographs were compared with the
remaining review flags. The audit closed **13 earlier log entries across 10
findings**: three corrected cells, six corroborated readings and one explained
component relationship.

| Printed page | Earlier transcription | Applied correction |
| --- | --- | --- |
| 43 | SH40A1D | SH40AD |
| 66 | SH975C, water-pipe connection clip | SH976C |
| 97 | First transmission-frame rivet: 1½″ long | 1⅛″ long; diameter remains ½″ |

Other resolutions include confirming **606 radiator tubes** from two cores of
303 tubes each, identifying washer **8209** through Plate 16, and using note (go)
to explain the shared **SH599A** component code in left and right manifold
assemblies.

One new source discrepancy was logged: the plain tachometer-shaft bushing is
printed **D22920 on page 44** and **D29920 on page 110**. Both readings remain.
The current review log contains **113 open and 99 resolved entries**. Some entries
cover general proofreading or layout, so these totals are not counts of uncertain
characters.

See `Transcription_Ambiguity_Audit.pdf`, `TRANSCRIPTION_AUDIT.md` and
`audit/ambiguity_audit.json` for the evidence and remaining conflicts.
`audit/review_before_context_audit.json` preserves the preceding review log.
A confirmed reading establishes what the source says; it does not by itself
establish that a printed dimension or specification is correct.

## Validation and remaining work

The saved Scribus document was reopened and all 25,682 text frames checked, with
**no overflow or unexpected line counts**. All 314 PDF pages were rendered;
page dimensions, embedded fonts and original-folio navigation were verified.
The revised cells and audit report were visually inspected.

For the latest transcription audit, comparison with the preceding delivered
project established that only the three intended cells changed. All native object
geometry, all 314 source JPEGs and all 31 figure assets were preserved. The other
**311 PDF pages rendered identically**. These checks are recorded in
`audit/context_delivery_validation.json`, with supporting native, reopen and PDF
validation records. Earlier geometry validation files document the preceding
figure-refinement stage.

Remaining work includes independent proofreading of small codes, fractions,
quantities and prices; investigation of contradictory original entries; and
further review of figures with limited geometric references. Physical page size,
foldout size, lens effects and interior drawing scale remain uncalibrated.

For subsequent CAD research, the transcription and illustrations provide part
identities, assembly relationships and visual references. Dimensions inferred
from image measurements should remain provisional until supported by explicit
source dimensions or independent evidence.

## Files and use

| File or directory | Purpose |
| --- | --- |
| `SNL_G13_Pilot.sla` | Complete editable Scribus document; “Pilot” is the retained working filename |
| `SNL_G13_Pilot.pdf` | Complete reading and review export |
| `Foldout_Plate_2.sla` | Standalone wide-page foldout document |
| `sources/` | Unmodified source JPEGs |
| `assets/` | Linked corrected figure images |
| `data/` | Structured transcription and source reconciliation records |
| `fonts/` | C059 fonts, proof fonts and their license files |
| `calibration/` | Geometry controls, models, comparisons and plate decisions |
| `review.json` | Current transcription review log |
| `audit/` | Cross-book audit evidence and preservation checks |
| `PROJECT_STATUS.md` | Checkpoint status and earlier figure-refinement history |

Extract the full project package, install the three C059 OpenType fonts and open
`SNL_G13_Pilot.sla` in **Scribus 1.6.x or later**. Validation used Scribus 1.6.1.
Keep `assets/` beside the document. A rebuild is unnecessary for normal editing.
Use the bundled OpenType fonts: a system Type 1 font with the same name can have
different metrics. Substantial text changes may require adjusting frames because
the reconstruction deliberately preserves the original line and page breaks.

The package includes Python scripts for asset preparation, Scribus construction,
proof generation and validation. Principal entry points are `prepare_assets.py`,
`build_project.py`, `make_proofs.py` and `check_reopened.py`.
`audit_context.py` regenerates the recorded audit decisions, while
`apply_context_corrections.py` applies the three named corrections and checks the
native text. Preserve manual edits separately before rebuilding generated files.
Bundled fonts retain their accompanying license notices.

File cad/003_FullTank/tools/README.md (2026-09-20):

# Resumable delivery validation

Run `python3 cad/003_FullTank/tools/resume_validation.py` from the repository.
The current worker's 27 stages include its nominal geometry checks, STEP round
trips, relocation, independent rebuild/cache checks and 15 parameter trials.
Three newly completed stages end a worker cleanly; the coordinator starts the
next worker. Re-run the same command after an interrupted coordinator.

Completed stages are reused only when their authored inputs, runtime versions,
nominal native hashes, runner code and exact output file sets still match.
Failed or interrupted stages have no successful receipt and run again. The
original worker is wrapped in memory; every original check expression is
retained, and the transformed source and audit are saved with the checkpoints.
The runner rejects an unrecognized stage structure instead of silently omitting
new checks. Geometry, source data and the nominal build are not edited.

Checkpoints and the durable coordinator log/status live in
`build/verification/checkpoints` and `build/verification/runs`. Successful final
validation adds `reports/resumable_validation.json` and regenerates the delivery
manifest. Partial directories alone are never evidence of a completed check.

Regression checks: `python3 -m unittest discover -s cad/003_FullTank/tools -p 'test_*.py' -v`.

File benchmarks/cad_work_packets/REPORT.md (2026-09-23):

# CAD packet controller and tool-enabled trials

The CLI controller is implemented and the six baseline trials are complete.
The evidence supports **experimental medium effort for reviewed, bounded
implementation**, with independent checks and review. It does not justify
automatically reducing effort for unresolved research or new mechanisms.

The controller routes those uncertain cases to xhigh, preserves failures, and
keeps all candidates in shadow mode. The new FreeCAD skill captures reusable
runtime and assembly knowledge so workers need not rediscover it in each packet.

## Baseline: one paired trial per task

Requested model: GPT-6 Astra. Each fresh session could use local tools, with an
eight-minute CLI limit. No new FreeCAD skill was discoverable during these six
trials. See the frozen [protocol](PROTOCOL.md) and
[machine-readable summary](results/summary.json).

| Task | Medium | Xhigh |
| --- | --- | --- |
| Parameterized nested stack | Completed in 290.7 s; 70/70 checks | Timed out at 480.0 s; final CAD files absent |
| Cross-assembly placement repair | Completed in 131.9 s; 94/94 checks | Timed out at 480.0 s; saved files passed 94/94 in a separate diagnostic |
| Historical source conflict | Completed in 102.3 s; 16/16 checks | Completed in 238.3 s; 16/16 checks |

Medium completed 3/3 within the limit; xhigh completed 1/3. These are **delivery
results under a fixed budget**, not evidence that xhigh generated wrong geometry.
The five available complete artifact sets passed the applicable independent
geometry/source checks. The xhigh mount record remains failed because its CLI
session did not finish; its subsequent
[geometry diagnostic](results/timeout_diagnostics/shadow01_mount_xhigh/grade.json)
does not replace or erase that timeout. The unfinished xhigh stack cannot be
assessed as a completed model.

The stack trials exposed GUI initialization/view fitting and API-discovery costs.
Both investigated an unavailable `App::Link.getGlobalPlacement()` method and
offscreen GUI behavior. The xhigh mount candidate also spent effort preserving
native archive bytes across FreeCAD serialization, beyond the semantic geometry
and placement requirements. Its repair was geometrically correct. Medium used
geometric comparisons after reopening instead of rewriting archive internals.

Both source candidates correctly identified M1336 around M1333, retained the
printed spring **outside** diameter, rejected the inserted memo, and left
historical dimensions unresolved. Under the stipulated wire assumption, both
computed -23.8125 mm literal radial clearance and +1.5875 mm for the alternative
ID interpretation. Positive clearance was not treated as historical proof.
The xhigh explanation included additional provenance distinctions, but both
satisfied the defined source criteria.

## Usage and interpretation

Medium's three sessions reported 772,362 input tokens (701,056 cached input),
13,955 output tokens and 997 reasoning-output tokens. Its summed CLI time was
524.9 seconds. Xhigh's observed CLI time was 1,198.4 seconds, including the two
480-second limits; its uncapped completion times for those tasks are unknown.

**The two timed-out xhigh sessions did not emit completion usage. Their token
use is unknown, not zero.** Only its completed source session reported usage:
197,580 input tokens (172,416 cached), 7,053 output and 1,321 reasoning-output.
Therefore this experiment cannot establish an aggregate token-cost ratio between
efforts. No monetary estimate is inferred from ChatGPT-authenticated CLI usage.

These are cumulative multi-turn token fields, unlike the first pilot's single
no-tools responses. Controller implementation, fixture qualification, primary
reviewer effort and the separate skill test are outside these six CLI timings.
One repetition per task, two synthetic geometry fixtures, a supplied source
conflict and the fixed deadline are substantial limits. This is still an effort
comparison within Astra, not a comparison of different model families or a
qualification of general NURBS reconstruction.

## What the implementation protects

The [controller guide](../../tools/cad_packets/README.md) documents its commands.
Candidates can edit only their own workspace; supplied inputs are read-only.
Validators, controller records, sibling candidates and production CAD are outside
candidate access. A preflight checks each run's boundary before inference.
Independent validators consume saved CAD/data and never import the candidate's
builder. Review and staging are separate, and staging cannot overwrite a bundle
or update the main assembly.

The baseline audit verified six independent thread IDs, actual command use,
record/input hashes and all 249 pre-existing native FCStd files under `cad/`
(the delivery and existing experiments) unchanged. The CLI records requested
model/effort, but does not attest the model served. Candidate notes describe image
inspection and correctly report image-only details; this CLI event format did
not expose distinct image-view events. The primary reviewer independently
inspected the supplied originals rather than treating that claim as attestation.

Ten controller/review-gate tests passed. The CAD evaluator passed three reference
cases and rejected four deliberate defects before inference. Both completed
medium CAD builders also regenerated passing documents in fresh, restricted
workspaces. Saved installed and section views were inspected: they show the
expected stack arrangement and both repaired mounts. Numerical fit/clearance
acceptance comes from the CAD checks; preview tessellation alone cannot establish
submillimetre clearance.

## Reusable FreeCAD skill

[freecad-reconstruction](../../skills/freecad-reconstruction/SKILL.md) contains
focused instructions, runtime/assembly/source references, a headless launcher,
rigid link helpers and a real FreeCAD self-test. Nine helper checks passed,
including nested transforms, bores, native/STEP reopening, headless visibility
and rejection of unsupported scaled links or definition frames.

The skill distinguishes runtime failures from geometry failures, avoids needless
GUI startup for kernel work, preserves source uncertainty, and documents its
helpers' narrower contract. It does not claim support for arbitrary linked
assembly traversal or validated freeform fitting. Skill files are versioned and
can be supplied as hashed packet inputs; changing guidance creates a distinct
trial instead of silently changing an active comparison.

A separate [skill-assisted stack trial](results/skill01_stack_medium/result.json)
passed all 70 independent checks and a
[fresh sandbox rebuild](results/reproduction/skill01_stack_medium/result.json).
It read the supplied guidance, used the canonical world-shape helper and stayed
headless. Its CLI runtime was 285.5 seconds versus the baseline medium's 290.7;
command executions were 15 versus 19, and output tokens 7,369 versus 7,410.
It also chose to generate additional section views. These nearly equal runtimes
do **not demonstrate a speed gain**: this was one fresh session with changed
guidance, outside the frozen baseline comparison. Its reported usage was 404,018
input tokens (354,432 cached), 7,369 output and 990 reasoning-output tokens.

The skill is installed through the repository's `.agents/skills` symlink and was
discovered in the active Codex session without a restart. It can be invoked as
`$freecad-reconstruction`. The five completed sessions have result-bound
`benchmark_only` source/visual reviews by the primary AI reviewer; the timed-out
mount has a separate diagnostic review that preserves its failure status.
These reviews qualify benchmark evidence, not historical tank geometry.

The [final verification](results/verification.json) checks all seven independent
run records, unchanged inputs and native tank files, skill-resource hashes and
three successful fresh rebuilds. Repeating all seven completed commands reused
their records without inference or changing saved run evidence. An attempted
stage of a benchmark-only result was correctly rejected.

## Operating decision

Use this controller with reviewed work packets and the qualified FreeCAD helpers.
Keep medium experimental for explicit dimensions/interfaces and known part
families. Retain xhigh for source conflicts, new mechanisms and difficult
diagnosis, with a task-appropriate time budget. Review source interpretation and
relevant views before integrating any real tank geometry. The next useful
efficiency measurements should include delivery failures, correction cost and
the benefit of shared runtime knowledge, rather than reasoning tokens alone.

The CLI remains adequate for this workflow. App Server is not required by these
results; it remains an option if persistent threads or finer interaction become
necessary. No experimental tank geometry was promoted by this work.

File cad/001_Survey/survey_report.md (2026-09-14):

# Mark VIII tank: source survey and CAD preparation

**Survey date:** 13 September 2026  
**Repository revision:** `a938a6e475da3263ede6a68b956da6d613964c26`  
**Requested scope:** [cad/001_Survey/intent.txt](https://github.com/starseeker/MarkVIIILiberty/blob/a938a6e475da3263ede6a68b956da6d613964c26/cad/001_Survey/intent.txt), both survey passes and the geometry-readiness assessment.

The source collection supports a useful, traceable component inventory and the beginning of a parameterized vehicle layout. It does **not yet support a fully dimensioned, configuration-consistent detailed model of the complete tank**. The principal obstacles are proprietary commercial assemblies, undocumented interfaces and hole locations, conflicting dimensions, and differences between preliminary design, production, and later service configurations.

The deliverable is `mark_viii_parts.sqlite`, accompanied by its schema, frozen inputs, rebuild scripts, example queries, validation results, this report, and a snapshot of the repository's transcription/reconstruction text sources. It has **5,482 conservative canonical records**, **3,879 assembly/arrangement assertions**, and **1,054 records linked across sources**. These are inventory identities and source assertions, not the number of manufactured pieces in one tank. Assemblies, features, equipment sets, alternatives, and unresolved identities are explicitly distinguishable.

## 1. Source inventory and scope

| ID | Source | PDF pages | Pinned repository source |
| --- | --- | --- | --- |
| SNL | Standard Nomenclature List G-13 (30 March 1928) | 314 | [PDF 1](https://github.com/starseeker/MarkVIIILiberty/blob/a938a6e475da3263ede6a68b956da6d613964c26/references/1928-03-30_SNL_G13/1928-03-30_SNL_G13_MarkVIII_Liberty.pdf) |
| HB | Preliminary Handbook of the Mark VIII Tank (1918; 1925 reprint) | 251 | [PDF 1](https://github.com/starseeker/MarkVIIILiberty/blob/a938a6e475da3263ede6a68b956da6d613964c26/references/1925-03-06_Preliminary_Handbook_Mark_VIII_Tank/Preliminary_Han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), [PDF 2](https://github.com/starseeker/MarkVIIILiberty/blob/a938a6e475da3263ede6a68b956da6d613964c26/references/1925-03-06_Preliminary_Handbook_Mark_VIII_Tank/Preliminary_Han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), [PDF 3](https://github.com/starseeker/MarkVIIILiberty/blob/a938a6e475da3263ede6a68b956da6d613964c26/references/1925-03-06_Preliminary_Handbook_Mark_VIII_Tank/Preliminary_Han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), [PDF 4](https://github.com/starseeker/MarkVIIILiberty/blob/a938a6e475da3263ede6a68b956da6d613964c26/references/1925-03-06_Preliminary_Handbook_Mark_VIII_Tank/Preliminary_Han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), [PDF 5](https://github.com/starseeker/MarkVIIILiberty/blob/a938a6e475da3263ede6a68b956da6d613964c26/references/1925-03-06_Preliminary_Handbook_Mark_VIII_Tank/Preliminary_Han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) |
| LIB | The 12 Cylinder Liberty Aero Engine (September 1918) | 162 | [PDF 1](https://github.com/starseeker/MarkVIIILiberty/blob/a938a6e475da3263ede6a68b956da6d613964c26/references/1918-09_12_Cylinder_Liberty_Aero_Engine/1918-09_12_Cylinder_Li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) |
| GUN | Hotchkiss 2.244-inch 6-pdr 6-cwt Mk II Gun with Tank Mounting (1919) | 32 | [PDF 1](https://github.com/starseeker/MarkVIIILiberty/blob/a938a6e475da3263ede6a68b956da6d613964c26/references/1919-08-15_Handbook_QF_Hotchkiss_2.244in_6pdr/1919-08-15_Handb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) |
| JORDAN | Harry B. Jordan, Manufacture of Mark VIII Tanks (1920), pp. 27-33 | 8 | [PDF 1](https://github.com/starseeker/MarkVIIILiberty/blob/a938a6e475da3263ede6a68b956da6d613964c26/references/1920-07_Manufacture_of_Mark_VIII_Tanks/1920-07_Manufacture_of_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) |
| PATENT | Herbert W. Alden, U.S. Patent 1,366,550 (1921) | 4 | [PDF 1](https://github.com/starseeker/MarkVIIILiberty/blob/a938a6e475da3263ede6a68b956da6d613964c26/references/1921-01-25_US1366550A/US1366550A_cleanup.pdf) |

The database indexes all **771 PDF pages** from the ten repository PDFs. It imports all **7,571 SNL table rows**, all **2,082 handbook nomenclature rows**, and **353 handbook legend rows**, plus 196 specification statements. A reviewed supplement contributes 345 component/feature/arrangement mentions from all six sources and 59 scalar geometry/count anchors; seven gun spare mentions reuse the corresponding installed-component identity. Two additional nominal sphere diameters are normalized from SNL descriptions.

The SNL rows resolve into 3,285 catalogue entries, 3,540 composed-of component rows, 681 composition markers, 40 continuation headings, and 25 continuation-text rows. Headings do not become manufactured parts. Two empty numeric handbook legend references, `21153`, are preserved for review without inventing a physical object. The blank description at handbook M-2188 is retained as a source deficiency.

**Coverage limit:** the table import is exhaustive against the preserved structured table inputs. The prose supplement is a reviewed component survey, not a proof that every incidental noun, hidden image label, commercial internal piece, or unnamed fastener in every photograph has been enumerated. The SNL itself says that some commercial subassembly parts are omitted, supplier information must be obtained separately, and a spare/accessory addendum is intended for Changes No. 1. Those are known holes in the source collection, not zero-piece assemblies. See SNL notes (b), (gy), and (gam), pp. 308–310.

### Transcription preservation and earlier sessions

Current repository data was preferable to re-extracting dense reconstructed tables from PDF. The survey freezes the table data, Liberty master transcription, gun line data, Jordan and patent reviewed transcription, all six errata files, and searchable PDF page text. It also bundles **597 tracked text/data/script files** from the six reconstruction projects under `source_transcription_snapshot/`, preserving the native transcription and review material at the surveyed commit. Large original PDFs and image assets remain in the repository; their consumed-source hashes and pinned paths are recorded.

A search of earlier session context identified the prior handbook feasibility study and handbook/Liberty master PDFs, but returned no additional recoverable complete transcript ZIP or missing transcript path. Therefore this package does not claim to contain a newly recovered full conversation archive. The earlier evidence also recorded a handbook insert that had not been separately located. That gap remains open. The existing SNL Plate 2 foldout is a separate, valuable longitudinal section. Details and the bounded recovery result are in `reports/source_recovery.md`.

## 2. First pass: requirements and schema

The schema treats **a source assertion, a canonical part identity, an occurrence in an assembly, and a geometric parameter as different things**. This separation is necessary to preserve conflicting values and repeated mentions without silently creating a false bill of materials.

| Tables | Purpose and interpretation |
| --- | --- |
| sources, source_files, source_pages | Document identity and applicability, SHA-256 of consumed files, one-based PDF page and printed-page mapping; full searchable page text. |
| source_records | Immutable raw JSON and description for each imported row or reviewed statement, including source path and locator. |
| parts | Stable survey ID, descriptive name, kind, identity basis, subsystem, initial readiness and missing geometry. |
| part_identifiers | Namespaced piece marks, manufacturer cross-references, drawing references and plate callouts; raw spelling retained. |
| part_evidence, part_relations | Evidence behind an identity and related components whose interchangeability is not established. |
| assembly_edges, quantities | Explicit composed-of contents, reviewed arrangements, raw counts and their scopes. No automatic whole-vehicle roll-up. |
| dimensions | Raw dimensional statement, optional reviewed scalar/unit/mm conversion, status and interpretation. Most rows remain verbatim dimensional descriptions. |
| figures, part_figures | Source plate/figure inventory and figure/legend references associated with parts. |
| notes, part_notes | SNL note text and linked qualifications, including substitution and quantity meanings. |
| variants, part_variants | Preliminary, production, replacement, future, aircraft, patent, shipping and spare applicability. |
| issues, issue_parts, review_queue | Inherited errata, new deductions/conflicts, affected part links, and unresolved identity/label cases. |
| research_leads, lead_parts | Primary-source candidates and failed searches, verification level, priority, benefit and related parts. |
| coverage, records_fts, pages_fts | Audit counts and full-text search. FTS5 is required for a complete rebuild. |

`schema.sql` defines the schema. The `v_parts`, `v_source_evidence`, `v_bom_edges`, `v_cross_source_parts`, `v_reviewed_dimensions`, and `v_geometry_queue` views support ordinary inspection. `examples.sql` contains ready-to-run queries.

### Identity and quantity rules

1. Prefer explicit piece marks within a namespace; keep manufacturer numbers, drawing references and figure callouts distinct. For example, SNL's Ordnance column explicitly allows a piece mark **or** a drawing number. Numeric-leading reference `679A` belongs to four distinct ring/pinion objects; it is not a single part identity.
2. Normalize spaces, case, and the hyphen between a letter prefix and its digits for lookup, retaining the original text. Do not strip arbitrary drawing prefixes to manufacture an aircraft-to-tank match.
3. Reconcile exact handbook-to-SNL marks when there is one credible role match. Preserve multiple matches in the review queue. A bare stud and an assembly incorporating that stud may share a mark and still need different records.
4. Unnumbered SNL description fingerprints and assembly descriptions provide provisional consolidation. Unnumbered handbook entries and reviewed aircraft/patent objects remain separate unless evidence establishes identity. Thus some real-world duplicates remain deliberately unresolved.
5. Keep the catalogue quantity column, written quantity per named parent, parenthetical total, handbook number per machine, and carried spare quantity separate. Never add these columns together. Parenthetical totals and the asterisk note often refer to a wider unit than the immediate list.
6. Assembly edges express source composition or arrangement, not transformation matrices, verified fits or an approved vehicle BOM. Alternative versions must be selected before any eventual quantity roll-up.

Canonical names are representative source labels, not corrected engineering specifications. Consult dimensions and issues before using a dimension embedded in a name. Source row IDs remain stable within the frozen input. The `140b` handbook table key is retained in its record ID to distinguish a second legend on printed page 140; the printed-page field is normalized to 140.

## 3. Second pass: population and reconciliation

The resulting database contains 10,606 source records, 7,585 identifier assertions, 9,628 part-evidence links, 9,646 quantity assertions, 2,029 dimension/specification statements, 44 SNL notes, 108 issues/source notes, and 15 research leads. There are 295 figure-index entries: 34 SNL plates, 143 handbook plates, 102 Liberty index entries, 13 gun plates including A–C, and three patent figures. An index entry is not necessarily an independent view or a calibrated geometric constraint.

The inventory includes 4,692 components, 755 assemblies, 29 integral features, four consumables, one equipment set, and one configuration group. Aircraft-only attachments, patent features, and spare equipment do not become extra installed tank pieces. The 37 review entries comprise 23 identifier-collision records, 11 ambiguous cross-source matches, two unlabelled numeric references, and one missing description. These are review records, not necessarily 37 independent physical ambiguities.

### Configuration must be selected explicitly

For an initial model of the **Rock Island production tank**, use the 1919–1920 production account for configuration and the SNL for identified service components, retaining dated replacement exceptions. The preliminary handbook is valuable for arrangement but cannot be treated as an exact American production specification. This is a recommended modeling baseline, not a claim that the documents fully establish one serial-numbered tank's fit.

| Question | Evidence | Disposition |
| --- | --- | --- |
| Fuel tanks | HB pp. 9,29,33: three 80-gallon tanks; Jordan pp. 27,29: three 50-gallon tanks. | Separate preliminary and production assemblies. Capacity is not sufficient to determine external dimensions; gallon convention remains unconverted. |
| Machine guns/stowage | HB pp. 9,171,175,180,182: Hotchkiss installation, nominally seven guns; Jordan p. 27: five Brownings. | Retain different armament and ammunition-stowage configurations. Require production installation evidence before locating all mounts. |
| Carburetors | Jordan pp. 29,32 replaces Zenith with Ball & Ball in production. SNL p. 57 and note (gx), p. 309, orders Zenith substitution under O.C.M. 2344 of 1 Sept. 1922. | Chronology reconciles the apparent contradiction. Aircraft Claudel-Hobson H.C.7 remains a reference alternative, not demonstrated tank equipment. |
| Electrical equipment | Jordan p. 29 counts/voltages conflict with SNL pp. 14,100,123 and handbook wiring. | Use the technical wiring/catalogue for a dated fit; do not infer equipment count or wiring from Jordan alone. |
| Pistons and aircraft attachments | LIB describes aircraft piston variants; SNL distinguishes LQ466A and SH1020A. HB p. 95 excludes the propeller hub from the Ordnance engine. | Keep original tank, service replacement and aircraft geometry distinct. C.C. synchronizer and propeller hardware remain aircraft reference objects. |
| Future production | SNL notes (gt) and (gv), p. 309, distinguish gauge and electrical-box fits. | Future-proposed equipment does not prove that tanks were built with it. |
| Patent sponson | Alden specification and three figures explain hinged/retracted relationships. | Useful kinematic evidence; no assumed exact dimensional or serial-production equivalence. |
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

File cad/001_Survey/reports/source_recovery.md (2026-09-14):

# Source preservation and prior-session recovery

The user authorized recovering needed transcription material from earlier PDF-creation sessions when it was absent from the repository, and including it in this effort's ZIP.

## Result

The current repository at `a938a6e475da3263ede6a68b956da6d613964c26` contains structured SNL tables and notes, handbook table and reconstruction data, the Liberty master transcription, gun line data, and Jordan/patent reviewed transcriptions. Those were used directly. The package freezes the inputs consumed by the survey and additionally preserves 597 tracked project text/data/script files
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

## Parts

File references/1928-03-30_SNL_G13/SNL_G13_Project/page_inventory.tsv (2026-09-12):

printed_label | pilot_page | supplied | page_type | source_filename | status
I | 1 | True | front matter | cover001.jpg | reconstructed; needs independent proofreading
II | 2 | True | front matter | cover002.jpg | reconstructed; needs independent proofreading
1 | 3 | True | title leaf | p001.jpg | reconstructed; needs independent proofreading
2 | 4 | True | parts table | p002.jpg | reconstructed; needs independent proofreading
3 | 5 | True | parts table | p003.jpg | reconstructed; needs independent proofreading
4 | 6 | True | parts table | p004.jpg | reconstructed; needs independent proofreading
5 | 7 | True | parts table | p005.jpg | reconstructed; needs independent proofreading
6 | 8 | True | parts table | p006.jpg | reconstructed; needs independent proofreading
7 | 9 | True | parts table | p007.jpg | reconstructed; needs independent proofreading
8 | 10 | True | parts table | p008.jpg | reconstructed; needs independent proofreading
9 | 11 | True | parts table | p009.jpg | reconstructed; needs independent proofreading
10 | 12 | True | parts table | p010.jpg | reconstructed; needs independent proofreading
11 | 13 | True | parts table | p011.jpg | reconstructed; needs independent proofreading
12 | 14 | True | parts table | p012.jpg | reconstructed; needs independent proofreading
13 | 15 | True | parts table | p013.jpg | reconstructed; needs independent proofreading
14 | 16 | True | parts table | p014.jpg | reconstructed; needs independent proofreading
15 | 17 | True | parts table | p015.jpg | reconstructed; needs independent proofreading
16 | 18 | True | parts table | p016.jpg | reconstructed; needs independent proofreading
17 | 19 | True | parts table | p017.jpg | reconstructed; needs independent proofreading
18 | 20 | True | parts table | p018.jpg | reconstructed; needs independent proofreading
19 | 21 | True | parts table | p019.jpg | reconstructed; needs independent proofreading
20 | 22 | True | parts table | p020.jpg | reconstructed; needs independent proofreading
21 | 23 | True | parts table | p021.jpg | reconstructed; needs independent proofreading
22 | 24 | True | parts table | p022.jpg | reconstructed; needs independent proofreading
23 | 25 | True | parts table | p023.jpg | reconstructed; needs independent proofreading
24 | 26 | True | parts table | p024.jpg | reconstructed; needs independent proofreading
25 | 27 | True | parts table | p025.jpg | reconstructed; needs independent proofreading
26 | 28 | True | parts table | p026.jpg | reconstructed; needs independent proofreading
27 | 29 | True | parts table | p027.jpg | reconstructed; needs independent proofreading
28 | 30 | True | parts table | p028.jpg | reconstructed; needs independent proofreading
29 | 31 | True | parts table | p029.jpg | reconstructed; needs independent proofreading
30 | 32 | True | parts table | p030.jpg | reconstructed; needs independent proofreading
31 | 33 | True | parts table | p031.jpg | reconstructed; needs independent proofreading
32 | 34 | True | parts table | p032.jpg | reconstructed; needs independent proofreading
33 | 35 | True | parts table | p033.jpg | reconstructed; needs independent proofreading
34 | 36 | True | parts table | p034.jpg | reconstructed; needs independent proofreading
35 | 37 | True | parts table | p035.jpg | reconstructed; needs independent proofreading
36 | 38 | True | parts table | p036.jpg | reconstructed; needs independent proofreading
37 | 39 | True | parts table | p037.jpg | reconstructed; needs independent proofreading
38 | 40 | True | parts table | p038.jpg | reconstructed; needs independent proofreading
39 | 41 | True | parts table | p039.jpg | reconstructed; needs independent proofreading
40 | 42 | True | parts table | p040.jpg | reconstructed; needs independent proofreading
41 | 43 | True | parts table | p041.jpg | reconstructed; needs independent proofreading
42 | 44 | True | parts table | p042.jpg | reconstructed; needs independent proofreading
43 | 45 | True | parts table | p043.jpg | reconstructed; needs independent proofreading
44 | 46 | True | parts table | p044.jpg | reconstructed; needs independent proofreading
45 | 47 | True | parts table | p045.jpg | reconstructed; needs independent proofreading
46 | 48 | True | parts table | p046.jpg | reconstructed; needs independent proofreading
47 | 49 | True | parts table | p047.jpg | reconstructed; needs independent proofreading
48 | 50 | True | parts table | p048.jpg | reconstructed; needs independent proofreading
49 | 51 | True | parts table | p049.jpg | reconstructed; needs independent proofreading
50 | 52 | True | parts table | p050.jpg | reconstructed; needs independent proofreading
51 | 53 | True | parts table | p051.jpg | reconstructed; needs independent proofreading
52 | 54 | True | parts table | p052.jpg | reconstructed; needs independent proofreading
53 | 55 | True | parts table | p053.jpg | reconstructed; needs independent proofreading
54 | 56 | True | parts table | p054.jpg | reconstructed; needs independent proofreading
55 | 57 | True | parts table | p055.jpg | reconstructed; needs independent proofreading
56 | 58 | True | parts table | p056.jpg | reconstructed; needs independent proofreading
57 | 59 | True | parts table | p057.jpg | reconstructed; needs independent proofreading
58 | 60 | True | parts table | p058.jpg | reconstructed; needs independent proofreading
59 | 61 | True | parts table | p059.jpg | reconstructed; needs independent proofreading
60 | 62 | True | parts table | p060.jpg | reconstructed; needs independent proofreading
61 | 63 | True | parts table | p061.jpg | reconstructed; needs independent proofreading
62 | 64 | True | parts table | p062.jpg | reconstructed; needs independent proofreading
63 | 65 | True | parts table | p063.jpg | reconstructed; needs independent proofreading
64 | 66 | True | parts table | p064.jpg | reconstructed; needs independent proofreading
65 | 67 | True | parts table | p065.jpg | reconstructed; needs independent proofreading
66 | 68 | True | parts table | p066.jpg | reconstructed; needs independent proofreading
67 | 69 | True | parts table | p067.jpg | reconstructed; needs independent proofreading
68 | 70 | True | parts table | p068.jpg | reconstructed; needs independent proofreading
69 | 71 | True | parts table | p069.jpg | reconstructed; needs independent proofreading
70 | 72 | True | parts table | p070.jpg | reconstructed; needs independent proofreading
71 | 73 | True | parts table | p071.jpg | reconstructed; needs independent proofreading
72 | 74 | True | parts table | p072.jpg | reconstructed; needs independent proofreading
73 | 75 | True | parts table | p073.jpg | reconstructed; needs independent proofreading
74 | 76 | True | parts table | p074.jpg | reconstructed; needs independent proofreading
75 | 77 | True | parts table | p075.jpg | reconstructed; needs independent proofreading
76 | 78 | True | parts table | p076.jpg | reconstructed; needs independent proofreading
77 | 79 | True | parts table | p077.jpg | reconstructed; needs independent proofreading
78 | 80 | True | parts table | p078.jpg | reconstructed; needs independent proofreading
79 | 81 | True | parts table | p079.jpg | reconstructed; needs independent proofreading
80 | 82 | True | parts table | p080.jpg | reconstructed; needs independent proofreading
81 | 83 | True | parts table | p081.jpg | reconstructed; needs independent proofreading
82 | 84 | True | parts table | p082.jpg | reconstructed; needs independent proofreading
83 | 85 | True | parts table | p083.jpg | reconstructed; needs independent proofreading
84 | 86 | True | parts table | p084.jpg | reconstructed; needs independent proofreading
85 | 87 | True | parts table | p085.jpg | reconstructed; needs independent proofreading
86 | 88 | True | parts table | p086.jpg | reconstructed; needs independent proofreading
87 | 89 | True | parts table | p087.jpg | reconstructed; needs independent proofreading
88 | 90 | True | parts table | p088.jpg | reconstructed; needs independent proofreading
89 | 91 | True | parts table | p089.jpg | reconstructed; needs independent proofreading
90 | 92 | True | parts table | p090.jpg | reconstructed; needs independent proofreading
91 | 93 | True | parts table | p091.jpg | reconstructed; needs independent proofreading
92 | 94 | True | parts table | p092.jpg | reconstructed; needs independent proofreading
93 | 95 | True | parts table | p093.jpg | reconstructed; needs independent proofreading
94 | 96 | True | parts table | p094.jpg | reconstructed; needs independent proofreading
95 | 97 | True | parts table | p095.jpg | reconstructed; needs independent proofreading
96 | 98 | True | parts table | p096.jpg | reconstructed; needs independent proofreading
97 | 99 | True | parts table | p097.jpg | reconstructed; needs independent proofreading
98 | 100 | True | parts table | p098.jpg | reconstructed; needs independent proofreading
99 | 101 | True | parts table | p099.jpg | reconstructed; needs independent proofreading
100 | 102 | True | parts table | p100.jpg | reconstructed; needs independent proofreading
101 | 103 | True | parts table | p101.jpg | reconstructed; needs independent proofreading
102 | 104 | True | parts table | p102.jpg | reconstructed; needs independent proofreading
103 | 105 | True | parts table | p103.jpg | reconstructed; needs independent proofreading
104 | 106 | True | parts table | p104.jpg | reconstructed; needs independent proofreading
105 | 107 | True | parts table | p105.jpg | reconstructed; needs independent proofreading
106 | 108 | True | parts table | p106.jpg | reconstructed; needs independent proofreading
107 | 109 | True | parts table | p107.jpg | reconstructed; needs independent proofreading
108 | 110 | True | parts table | p108.jpg | reconstructed; needs independent proofreading
109 | 111 | True | parts table | p109.jpg | reconstructed; needs independent proofreading
110 | 112 | True | parts table | p110.jpg | reconstructed; needs independent proofreading
111 | 113 | True | parts table | p111.jpg | reconstructed; needs independent proofreading
112 | 114 | True | parts table | p112.jpg | reconstructed; needs independent proofreading
113 | 115 | True | parts table | p113.jpg | reconstructed; needs independent proofreading
114 | 116 | True | parts table | p114.jpg | reconstructed; needs independent proofreading
115 | 117 | True | parts table | p115.jpg | reconstructed; needs independent proofreading
116 | 118 | True | parts table | p116.jpg | reconstructed; needs independent proofreading
117 | 119 | True | parts table | p117.jpg | reconstructed; needs independent proofreading
118 | 120 | True | parts table | p118.jpg | reconstructed; needs independent proofreading
119 | 121 | True | parts table | p119.jpg | reconstructed; needs independent proofreading
120 | 122 | True | parts table | p120.jpg | reconstructed; needs independent proofreading
121 | 123 | True | parts table | p121.jpg | reconstructed; needs independent proofreading
122 | 124 | True | parts table | p122.jpg | reconstructed; needs independent proofreading
123 | 125 | True | parts table | p123.jpg | reconstructed; needs independent proofreading
124 | 126 | True | parts table | p124.jpg | reconstructed; needs independent proofreading
125 | 127 | True | parts table | p125.jpg | reconstructed; needs independent proofreading
126 | 128 | True | parts table | p126.jpg | reconstructed; needs independent proofreading
127 | 129 | True | parts table | p127.jpg | reconstructed; needs independent proofreading
128 | 130 | True | parts table | p128.jpg | reconstructed; needs independent proofreading
129 | 131 | True | parts table | p129.jpg | reconstructed; needs independent proofreading
130 | 132 | True | parts table | p130.jpg | reconstructed; needs independent proofreading
131 | 133 | True | parts table | p131.jpg | reconstructed; needs independent proofreading
132 | 134 | True | parts table | p132.jpg | reconstructed; needs independent proofreading
133 | 135 | True | parts table | p133.jpg | reconstructed; needs independent proofreading
134 | 136 | True | parts table | p134.jpg | reconstructed; needs independent proofreading
135 | 137 | True | parts table | p135.jpg | reconstructed; needs independent proofreading
136 | 138 | True | parts table | p136.jpg | reconstructed; needs independent proofreading
137 | 139 | True | parts table | p137.jpg | reconstructed; needs independent proofreading
138 | 140 | True | parts table | p138.jpg | reconstructed; needs independent proofreading
139 | 141 | True | parts table | p139.jpg | reconstructed; needs independent proofreading
140 | 142 | True | parts table | p140.jpg | reconstructed; needs independent proofreading
141 | 143 | True | parts table | p141.jpg | reconstructed; needs independent proofreading
142 | 144 | True | parts table | p142.jpg | reconstructed; needs independent proofreading
143 | 145 | True | parts table | p143.jpg | reconstructed; needs independent proofreading
144 | 146 | True | parts table | p144.jpg | reconstructed; needs independent proofreading
145 | 147 | True | parts table | p145.jpg | reconstructed; needs independent proofreading
146 | 148 | True | parts table | p146.jpg | reconstructed; needs independent proofreading
147 | 149 | True | parts table | p147.jpg | reconstructed; needs independent proofreading
148 | 150 | True | parts table | p148.jpg | reconstructed; needs independent proofreading
149 | 151 | True | parts table | p149.jpg | reconstructed; needs independent proofreading
150 | 152 | True | parts table | p150.jpg | reconstructed; needs independent proofreading
151 | 153 | True | parts table | p151.jpg | reconstructed; needs independent proofreading
152 | 154 | True | parts table | p152.jpg | reconstructed; needs independent proofreading
153 | 155 | True | parts table | p153.jpg | reconstructed; needs independent proofreading
154 | 156 | True | parts table | p154.jpg | reconstructed; needs independent proofreading
155 | 157 | True | parts table | p155.jpg | reconstructed; needs independent proofreading
156 | 158 | True | parts table | p156.jpg | reconstructed; needs independent proofreading
157 | 159 | True | parts table | p157.jpg | reconstructed; needs independent proofreading
158 | 160 | True | parts table | p158.jpg | reconstructed; needs independent proofreading
159 | 161 | True | parts table | p159.jpg | reconstructed; needs independent proofreading
160 | 162 | True | parts table | p160.jpg | reconstructed; needs independent proofreading
161 | 163 | True | parts table | p161.jpg | reconstructed; needs independent proofreading
162 | 164 | True | parts table | p162.jpg | reconstructed; needs independent proofreading
163 | 165 | True | parts table | p163.jpg | reconstructed; needs independent proofreading
164 | 166 | True | parts table | p164.jpg | reconstructed; needs independent proofreading
165 | 167 | True | parts table | p165.jpg | reconstructed; needs independent proofreading
166 | 168 | True | parts table | p166.jpg | reconstructed; needs independent proofreading
167 | 169 | True | parts table | p167.jpg | reconstructed; needs independent proofreading
168 | 170 | True | parts table | p168.jpg | reconstructed; needs independent proofreading
169 | 171 | True | parts table | p169.jpg | reconstructed; needs independent proofreading
170 | 172 | True | parts table | p170.jpg | reconstructed; needs independent proofreading
171 | 173 | True | parts table | p171.jpg | reconstructed; needs independent proofreading
172 | 174 | True | parts table | p172.jpg | reconstructed; needs independent proofreading
173 | 175 | True | parts table | p173.jpg | reconstructed; needs independent proofreading
174 | 176 | True | parts table | p174.jpg | reconstructed; needs independent proofreading
175 | 177 | True | parts table | p175.jpg | reconstructed; needs independent proofreading
176 | 178 | True | parts table | p176.jpg | reconstructed; needs independent proofreading
177 | 179 | True | parts table | p177.jpg | reconstructed; needs independent proofreading
178 | 180 | True | parts table | p178.jpg | reconstructed; needs independent proofreading
179 | 181 | True | parts table | p179.jpg | reconstructed; needs independent proofreading
180 | 182 | True | parts table | p180.jpg | reconstructed; needs independent proofreading
181 | 183 | True | parts table | p181.jpg | reconstructed; needs independent proofreading
182 | 184 | True | parts table | p182.jpg | reconstructed; needs independent proofreading
183 | 185 | True | parts table | p183.jpg | reconstructed; needs independent proofreading
184 | 186 | True | parts table | p184.jpg | reconstructed; needs independent proofreading
185 | 187 | True | parts table | p185.jpg | reconstructed; needs independent proofreading
186 | 188 | True | parts table | p186.jpg | reconstructed; needs independent proofreading
187 | 189 | True | parts table | p187.jpg | reconstructed; needs independent proofreading
188 | 190 | True | parts table | p188.jpg | reconstructed; needs independent proofreading
189 | 191 | True | parts table | p189.jpg | reconstructed; needs independent proofreading
190 | 192 | True | parts table | p190.jpg | reconstructed; needs independent proofreading
191 | 193 | True | parts table | p191.jpg | reconstructed; needs independent proofreading
192 | 194 | True | parts table | p192.jpg | reconstructed; needs independent proofreading
193 | 195 | True | parts table | p193.jpg | reconstructed; needs independent proofreading
194 | 196 | True | parts table | p194.jpg | reconstructed; needs independent proofreading
195 | 197 | True | parts table | p195.jpg | reconstructed; needs independent proofreading
196 | 198 | True | parts table | p196.jpg | reconstructed; needs independent proofreading
197 | 199 | True | parts table | p197.jpg | reconstructed; needs independent proofreading
198 | 200 | True | parts table | p198.jpg | reconstructed; needs independent proofreading
199 | 201 | True | parts table | p199.jpg | reconstructed; needs independent proofreading
200 | 202 | True | parts table | p200.jpg | reconstructed; needs independent proofreading
201 | 203 | True | parts table | p201.jpg | reconstructed; needs independent proofreading
202 | 204 | True | parts table | p202.jpg | reconstructed; needs independent proofreading
203 | 205 | True | parts table | p203.jpg | reconstructed; needs independent proofreading
204 | 206 | True | parts table | p204.jpg | reconstructed; needs independent proofreading
205 | 207 | True | parts table | p205.jpg | reconstructed; needs independent proofreading
206 | 208 | True | parts table | p206.jpg | reconstructed; needs independent proofreading
207 | 209 | True | parts table | p207.jpg | reconstructed; needs independent proofreading
208 | 210 | True | parts table | p208.jpg | reconstructed; needs independent proofreading
209 | 211 | True | parts table | p209.jpg | reconstructed; needs independent proofreading
210 | 212 | True | parts table | p210.jpg | reconstructed; needs independent proofreading
211 | 213 | True | parts table | p211.jpg | reconstructed; needs independent proofreading
212 | 214 | True | parts table | p212.jpg | reconstructed; needs independent proofreading
213 | 215 | True | parts table | p213.jpg | reconstructed; needs independent proofreading
214 | 216 | True | parts table | p214.jpg | reconstructed; needs independent proofreading
215 | 217 | True | parts table | p215.jpg | reconstructed; needs independent proofreading
216 | 218 | True | parts table | p216.jpg | reconstructed; needs independent proofreading
217 | 219 | True | parts table | p217.jpg | reconstructed; needs independent proofreading
218 | 220 | True | parts table | p218.jpg | reconstructed; needs independent proofreading
219 | 221 | True | parts table | p219.jpg | reconstructed; needs independent proofreading
220 | 222 | True | parts table | p220.jpg | reconstructed; needs independent proofreading
221 | 223 | True | parts table | p221.jpg | reconstructed; needs independent proofreading
222 | 224 | True | parts table | p222.jpg | reconstructed; needs independent proofreading
223 | 225 | True | parts table | p223.jpg | reconstructed; needs independent proofreading
224 | 226 | True | parts table | p224.jpg | reconstructed; needs independent proofreading
225 | 227 | True | parts table | p225.jpg | reconstructed; needs independent proofreading
226 | 228 | True | parts table | p226.jpg | reconstructed; needs independent proofreading
227 | 229 | True | parts table | p227.jpg | reconstructed; needs independent proofreading
228 | 230 | True | parts table | p228.jpg | reconstructed; needs independent proofreading
229 | 231 | True | parts table | p229.jpg | reconstructed; needs independent proofreading
230 | 232 | True | parts table | p230.jpg | reconstructed; needs independent proofreading
231 | 233 | True | parts table | p231.jpg | reconstructed; needs independent proofreading
232 | 234 | True | parts table | p232.jpg | reconstructed; needs independent proofreading
233 | 235 | True | parts table | p233.jpg | reconstructed; needs independent proofreading
234 | 236 | True | parts table | p234.jpg | reconstructed; needs independent proofreading
235 | 237 | True | parts table | p235.jpg | reconstructed; needs independent proofreading
236 | 238 | True | parts table | p236.jpg | reconstructed; needs independent proofreading
237 | 239 | True | parts table | p237.jpg | reconstructed; needs independent proofreading
238 | 240 | True | parts table | p238.jpg | reconstructed; needs independent proofreading
239 | 241 | True | parts table | p239.jpg | reconstructed; needs independent proofreading
240 | 242 | True | parts table | p240.jpg | reconstructed; needs independent proofreading
241 | 243 | True | parts table | p241.jpg | reconstructed; needs independent proofreading
242 | 244 | True | parts table | p242.jpg | reconstructed; needs independent proofreading
243 | 245 | True | parts table | p243.jpg | reconstructed; needs independent proofreading
244 | 246 | True | parts table | p244.jpg | reconstructed; needs independent proofreading
245 | 247 | True | parts table | p245.jpg | reconstructed; needs independent proofreading
246 | 248 | True | parts table | p246.jpg | reconstructed; needs independent proofreading
247 | 249 | True | parts table | p247.jpg | reconstructed; needs independent proofreading
248 | 250 | True | parts table | p248.jpg | reconstructed; needs independent proofreading
249 | 251 | True | parts table | p249.jpg | reconstructed; needs independent proofreading
250 | 252 | True | parts table | p250.jpg | reconstructed; needs independent proofreading
251 | 253 | True | parts table | p251.jpg | reconstructed; needs independent proofreading
252 | 254 | True | parts table | p252.jpg | reconstructed; needs independent proofreading
253 | 255 | True | parts table | p253.jpg | reconstructed; needs independent proofreading
254 | 256 | True | parts table | p254.jpg | reconstructed; needs independent proofreading
255 | 257 | True | parts table | p255.jpg | reconstructed; needs independent proofreading
256 | 258 | True | parts table | p256.jpg | reconstructed; needs independent proofreading
257 | 259 | True | parts table | p257.jpg | reconstructed; needs independent proofreading
258 | 260 | True | parts table | p258.jpg | reconstructed; needs independent proofreading
259 | 261 | True | parts table | p259.jpg | reconstructed; needs independent proofreading
260 | 262 | True | parts table | p260.jpg | reconstructed; needs independent proofreading
261 | 263 | True | parts table | p261.jpg | reconstructed; needs independent proofreading
262 | 264 | True | parts table | p262.jpg | reconstructed; needs independent proofreading
263 | 265 | True | parts table | p263.jpg | reconstructed; needs independent proofreading
264 | 266 | True | parts table | p264.jpg | reconstructed; needs independent proofreading
265 | 267 | True | parts table | p265.jpg | reconstructed; needs independent proofreading
266 | 268 | True | parts table | p266.jpg | reconstructed; needs independent proofreading
267 | 269 | True | parts table | p267.jpg | reconstructed; needs independent proofreading
268 | 270 | True | parts table | p268.jpg | reconstructed; needs independent proofreading
269 | 271 | True | parts table | p269.jpg | reconstructed; needs independent proofreading
270 | 272 | True | parts table | p270.jpg | reconstructed; needs independent proofreading
271 | 273 | True | parts table | p271.jpg | reconstructed; needs independent proofreading
272 | 274 | True | parts table | p272.jpg | reconstructed; needs independent proofreading
273 | 275 | True | parts table | p273.jpg | reconstructed; needs independent proofreading
274 | 276 | True | parts table | p274.jpg | reconstructed; needs independent proofreading
275 | 277 | True | parts table | p275.jpg | reconstructed; needs independent proofreading
276 | 278 | True | parts table | p276.jpg | reconstructed; needs independent proofreading
277 | 279 | True | plate page | p277.jpg | original artwork; individually reviewed correction
278 | 281 | True | plate page | p278.jpg | original artwork; individually reviewed correction
279 | 282 | True | plate page | p279.jpg | original artwork; individually reviewed correction
280 | 283 | True | plate page | p280.jpg | original artwork; individually reviewed correction
281 | 284 | True | plate page | p281.jpg | original artwork; individually reviewed correction
282 | 285 | True | plate page | p282.jpg | original artwork; individually reviewed correction
283 | 286 | True | plate page | p283.jpg | original artwork; individually reviewed correction
284 | 287 | True | plate page | p284.jpg | original artwork; individually reviewed correction
285 | 288 | True | plate page | p285.jpg | original artwork; individually reviewed correction
286 | 289 | True | plate page | p286.jpg | original artwork; individually reviewed correction
287 | 290 | True | plate page | p287.jpg | original artwork; individually reviewed correction
288 | 291 | True | plate page | p288.jpg | original artwork; individually reviewed correction
289 | 292 | True | plate page | p289.jpg | original artwork; individually reviewed correction
290 | 293 | True | plate page | p290.jpg | original artwork; individually reviewed correction
291 | 294 | True | plate page | p291.jpg | original artwork; individually reviewed correction
292 | 295 | True | plate page | p292.jpg | original artwork; individually reviewed correction
293 | 296 | True | plate page | p293.jpg | original artwork; individually reviewed correction
294 | 297 | True | plate page | p294.jpg | original artwork; individually reviewed correction
295 | 298 | True | plate page | p295.jpg | original artwork; individually reviewed correction
296 | 299 | True | plate page | p296.jpg | original artwork; individually reviewed correction
297 | 300 | True | plate page | p297.jpg | original artwork; individually reviewed correction
298 | 301 | True | plate page | p298.jpg | original artwork; individually reviewed correction
299 | 302 | True | plate page | p299.jpg | original artwork; individually reviewed correction
300 | 303 | True | plate page | p300.jpg | original artwork; individually reviewed correction
301 | 304 | True | plate page | p301.jpg | original artwork; individually reviewed correction
302 | 305 | True | plate page | p302.jpg | original artwork; individually reviewed correction
303 | 306 | True | plate page | p303.jpg | original artwork; individually reviewed correction
304 | 307 | True | plate page | p304.jpg | original artwork; individually reviewed correction
305 | 308 | True | plate page | p305.jpg | original artwork; individually reviewed correction
306 | 309 | True | plate page | p306.jpg | original artwork; individually reviewed correction
307 | 310 | True | notes | p307.jpg | reconstructed; needs independent proofreading
308 | 311 | True | notes | p308.jpg | reconstructed; needs independent proofreading
309 | 312 | True | notes | p309.jpg | reconstructed; needs independent proofreading
310 | 313 | True | notes | p310.jpg | reconstructed; needs independent proofreading
311 | 314 | True | notes | p311.jpg | reconstructed; needs independent proofreading
Face p. 277 | 280 | True | foldout | p277_foldout.jpg | source artwork; provisional wide page

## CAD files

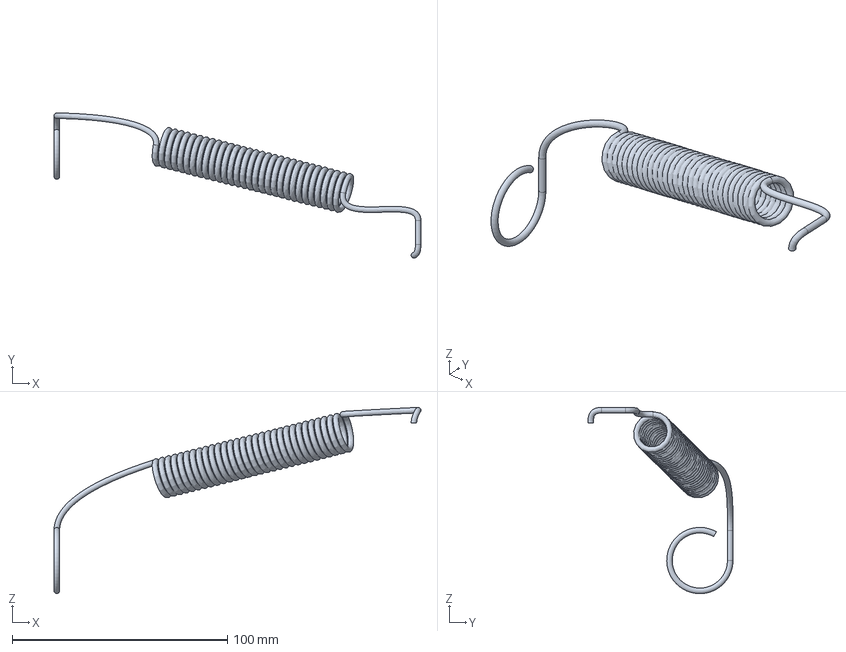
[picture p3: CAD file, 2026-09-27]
cad/003_FullTank/experiments/drive_chains/transmission_controls_study/redo01/diagnostics/sweep_export/sweep-exchange-probe/whole_parallel.step
170.5 x 67.4 x 86.5 mm

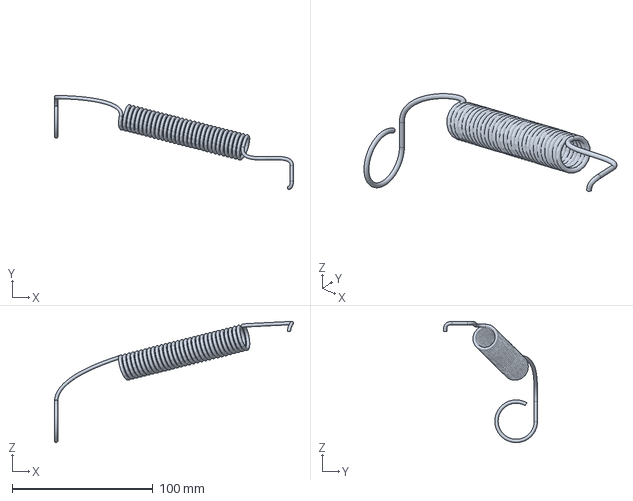
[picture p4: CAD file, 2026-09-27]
cad/003_FullTank/experiments/drive_chains/transmission_controls_study/redo01/diagnostics/sweep_export/sweep-exchange-variation/whole_parallel.step
170.1 x 67.0 x 86.2 mm

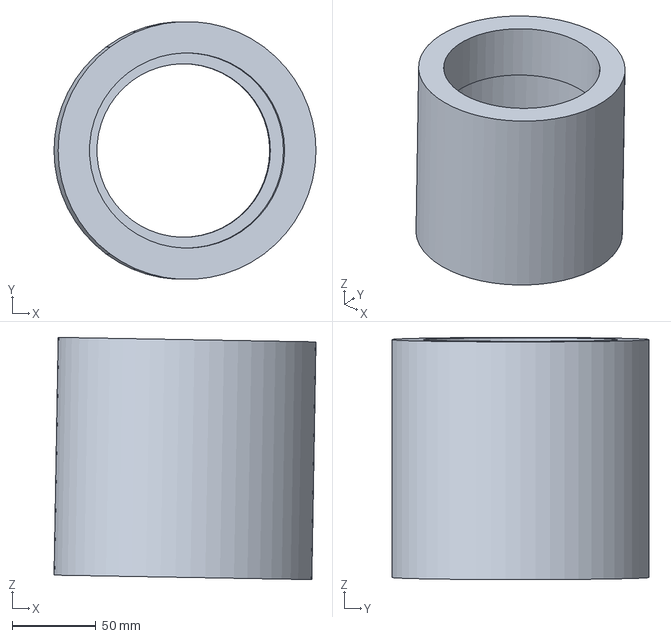
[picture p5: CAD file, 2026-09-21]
benchmarks/cad_reasoning/results/pilot_01/construction_high_1/grading/larger/bearing.step
156.3 x 153.5 x 144.5 mm

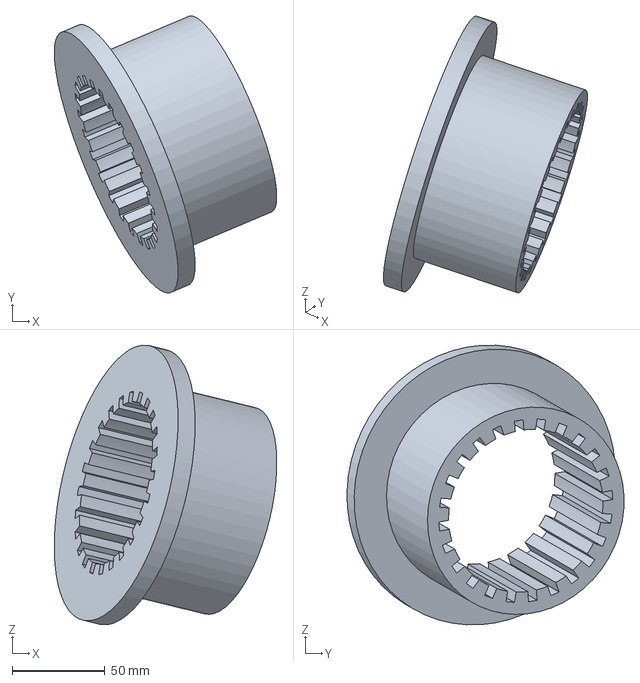
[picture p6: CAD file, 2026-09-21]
benchmarks/cad_reasoning/results/pilot_01/construction_high_1/grading/nominal/sleeve.step
119.7 x 149.0 x 150.3 mm

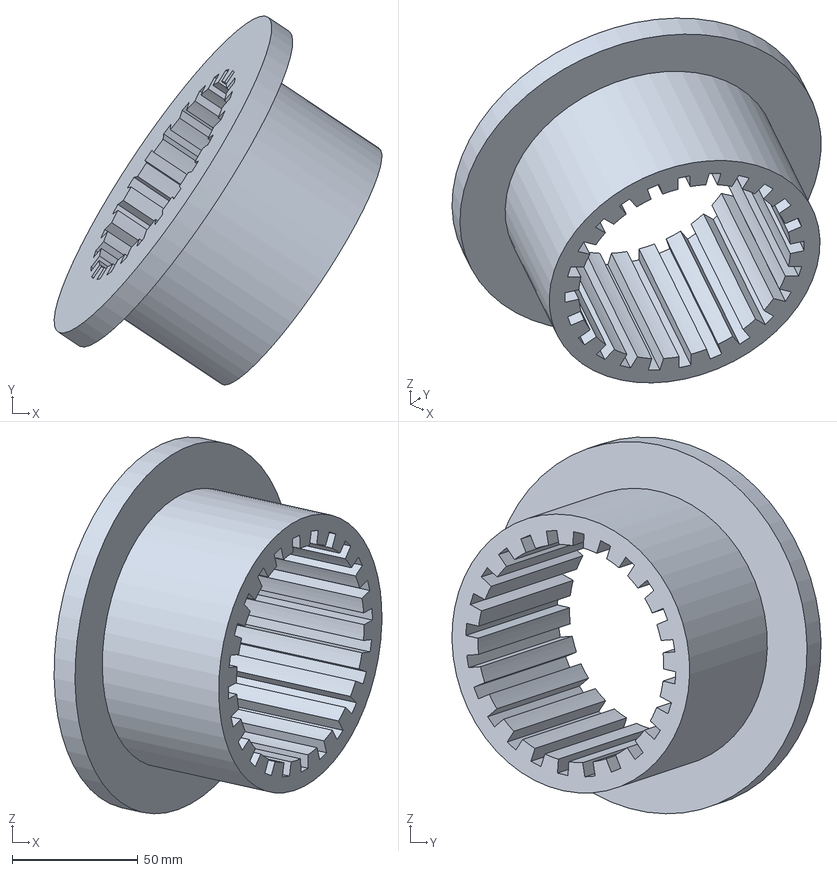
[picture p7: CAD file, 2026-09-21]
benchmarks/cad_reasoning/results/pilot_01/construction_high_1/grading/smaller/sleeve.step
130.4 x 146.8 x 149.9 mm

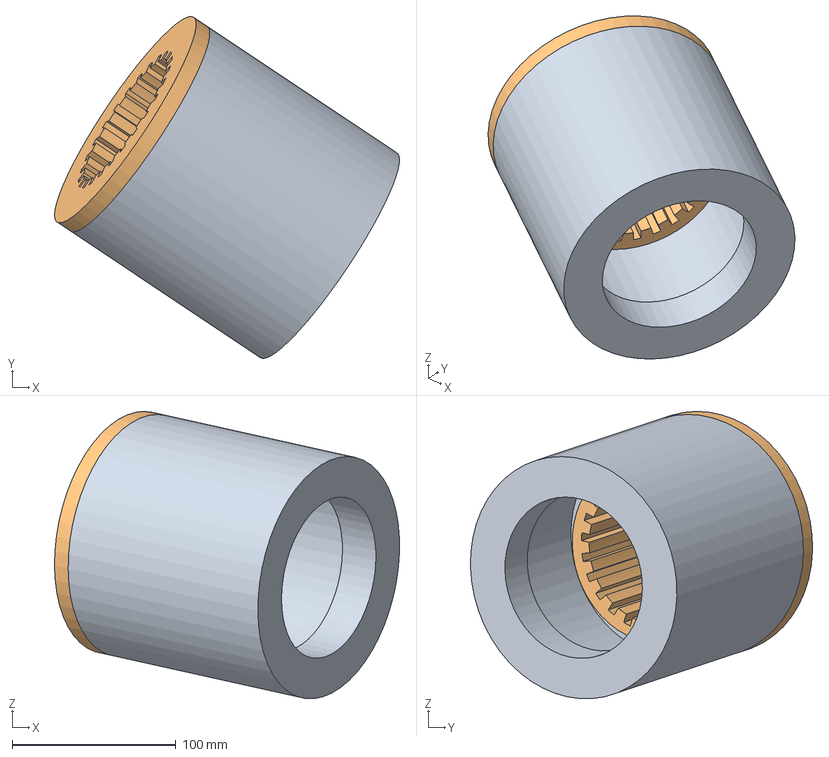
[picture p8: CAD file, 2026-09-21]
benchmarks/cad_reasoning/results/pilot_01/construction_high_1/grading_v2/smaller/candidate.FCStd
210.9 x 209.1 x 175.6 mm
bearing
sleeve

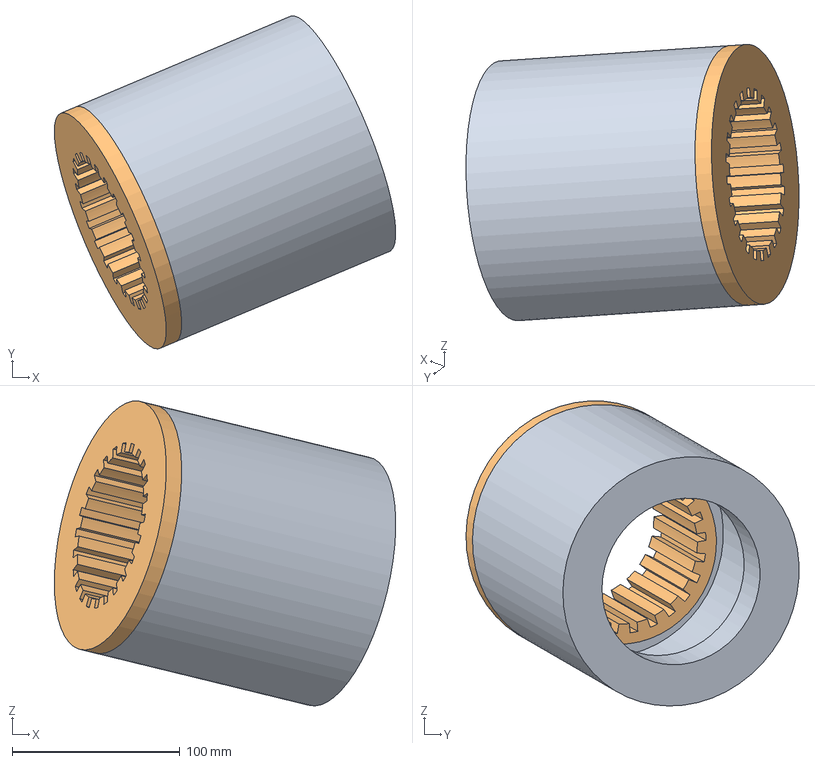
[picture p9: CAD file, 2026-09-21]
benchmarks/cad_reasoning/results/pilot_01/construction_high_2/grading/nominal/candidate.FCStd
203.2 x 198.2 x 181.5 mm
bearing
sleeve

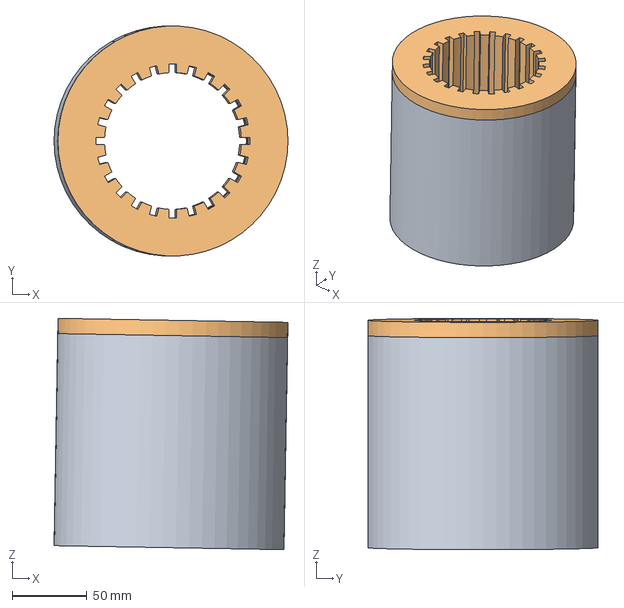
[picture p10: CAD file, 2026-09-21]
benchmarks/cad_reasoning/results/pilot_01/construction_high_2/grading_v2/larger/candidate.FCStd
156.4 x 153.5 x 154.7 mm
bearing
sleeve

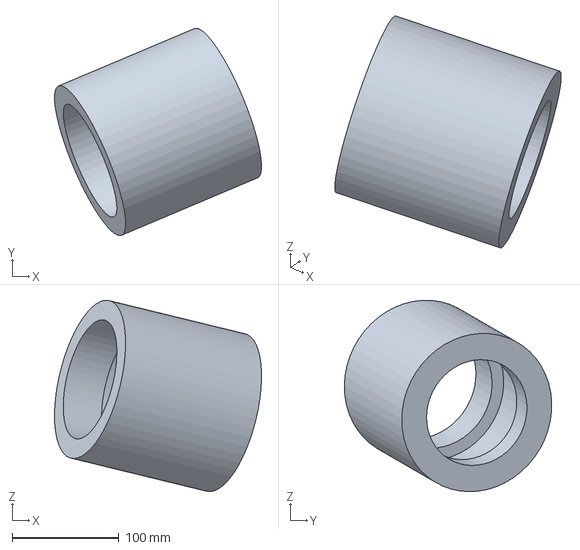
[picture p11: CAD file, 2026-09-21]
benchmarks/cad_reasoning/results/pilot_01/construction_high_2/grading_v2/nominal/bearing.step
194.0 x 194.4 x 179.3 mm

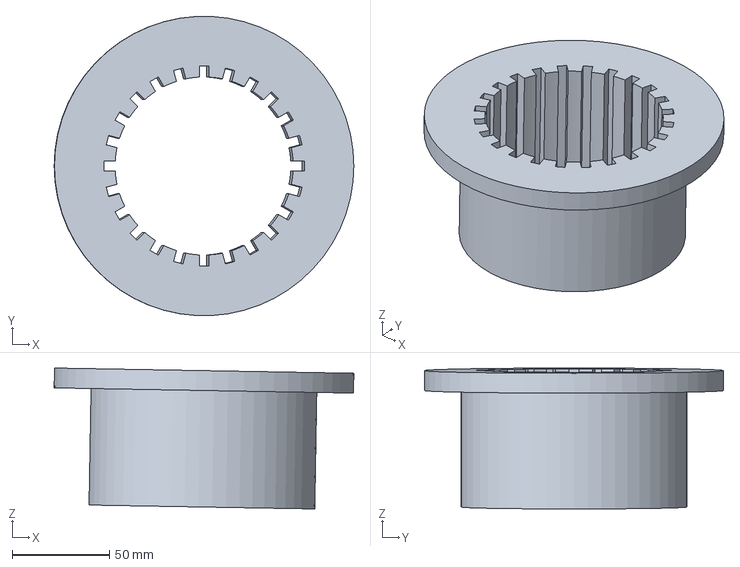
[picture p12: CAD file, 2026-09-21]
benchmarks/cad_reasoning/results/pilot_01/construction_high_3/grading/larger/sleeve.step
154.0 x 153.6 x 72.4 mm

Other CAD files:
benchmarks/cad_reasoning/results/pilot_01/construction_high_1/grading_v2/larger/bearing.step
benchmarks/cad_reasoning/results/pilot_01/construction_high_1/grading_v2/nominal/sleeve.step
benchmarks/cad_reasoning/results/pilot_01/construction_high_2/grading/larger/bearing.step
benchmarks/cad_reasoning/results/pilot_01/construction_high_2/grading/smaller/candidate.FCStd
benchmarks/cad_reasoning/results/pilot_01/construction_high_2/grading_v2/smaller/sleeve.step
benchmarks/cad_reasoning/results/pilot_01/construction_high_3/grading/nominal/sleeve.step
benchmarks/cad_reasoning/results/pilot_01/construction_high_3/grading/smaller/sleeve.step
benchmarks/cad_reasoning/results/pilot_01/construction_high_3/grading_v2/larger/candidate.FCStd
benchmarks/cad_reasoning/results/pilot_01/construction_high_1/grading/larger/candidate.FCStd
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

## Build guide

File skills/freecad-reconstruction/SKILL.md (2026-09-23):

---
name: freecad-reconstruction
description: Build and verify scripted FreeCAD BRep parts and linked assemblies, including evidence-led historical reconstruction, native/STEP exchange, and headless runtime troubleshooting.
---

# FreeCAD reconstruction

Use the project's existing builders, datums, source records and validators when
available. Keep historical interpretation separate from CAD execution: a valid,
well-fitting solid can still represent the wrong part.

## Choose the relevant guidance

- For scripted construction, transforms, saved files or interchange, read
  [assembly and validation](references/assembly-and-validation.md).
- On this Linux workstation, or when FreeCAD imports/GUI startup fail, read
  [local runtime](references/local-runtime.md). Prefer headless construction and
  an existing software renderer when an interactive view is unnecessary.
- When deriving geometry from drawings, catalogues or conflicting dimensions,
  read [source reconstruction](references/source-reconstruction.md).

For a bounded implementation, establish units, definition coordinates, parent
frames and interfaces before writing geometry. Preserve shared part definitions
and separate installed occurrences. Produce a reproducible builder plus the
native documents; say which dimensions update live and which need regeneration.

Use analytic surfaces for analytic features. Use B-spline/NURBS sections or patches
when the supported form needs them, retaining the curves, fitting assumptions and
residual checks. Do not infer additional dimensional certainty from surface smoothness.

Validate the actual saved artifacts independently of the builder's self-checks.
Check material and voids, parent-relative placement, neighboring interfaces, and
native/STEP reopening. Include a relevant parameter variation for reusable parts.
Read the source and inspect a suitable view/section before accepting reconstruction
geometry; distinguish an approximate feature from a source-supported one.

## Reusable helpers

`scripts/freecad_headless.py` launches a script with the installed snap runtime
and task-local settings. It also has `--probe`. It does not start a GUI or change
sandbox permissions. Use an already-qualified project launcher when appropriate.

`scripts/assembly_geometry.py` resolves rigid `App::Part` ancestry and direct
`App::Link` occurrences of identity-frame shape definitions. It rejects unsupported
scales and definition frames instead of guessing. For links to assemblies, scaled
links or external dependency trees, use or qualify the project's full traversal.

Run `scripts/self_test.py` through the headless launcher after changing these
helpers or upgrading the runtime. It tests transformed assembly geometry,
interchange/reopening and rejection of unsupported link forms. The helpers do
not implement or certify general freeform surface fitting.

## Improve from evidence

Add a narrowly scoped lesson when a real failure reveals a reusable cause. Record
the tested runtime and a reproducer for API or GUI behavior. Keep task-specific
piece marks and dimensions in their work packet, rather than turning them into
skill-wide rules. Freeze skill copies supplied to comparison trials; evolve the
next trial or packet revision separately.

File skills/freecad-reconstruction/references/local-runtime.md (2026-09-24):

# Local FreeCAD runtime

Verified on 22 September 2026: Python 3.12.3, FreeCAD 1.1.1, OCC 7.8.0,
`/snap/freecad/2741`, and Qt runtime `/snap/kf6-core24/64`.
Use `/snap/freecad/current` and `/snap/kf6-core24/current` to resolve the installed
paths, and record the versions actually loaded. These are local facts, not
assumptions to impose on another system.

## Headless first for geometry

Constructing BRep shapes, creating/linking objects, saving FCStd and exporting
STEP do not require `FreeCADGui.showMainWindow()`. Ordinary part/feature/link
`Visibility` properties are available headlessly in the tested release, although
`ViewObject` is absent; save/reopen and verify the required display state rather
than opening a GUI just to hide a definition library. For this skill's launcher:

```bash
python3 skills/freecad-reconstruction/scripts/freecad_headless.py --probe
python3 skills/freecad-reconstruction/scripts/freecad_headless.py --workdir .work/my_packet my_builder.py
```

The script path resolves relative to the invoking directory; relative files
opened by the builder resolve inside `--workdir`. Settings, cache and temporary
files stay under that work directory. This helper configures library paths; it
does not grant filesystem or network permissions. The controller's packet
launcher already supplies the runtime, so do not nest launchers unnecessarily.

In the tank pipeline, reuse `cad/003_FullTank/lib/runtime.py` when its GUI workflow
is required. Its output-directory argument must be absolute: relative Qt/XDG
paths have caused process aborts. Preserve task-local settings rather than sharing
the desktop profile or changing HOME/CODEX_HOME.

## GUI and rendering pitfalls

The offscreen Qt platform reports unsupported OpenGL widgets on this machine.
The tool-enabled trials observed stalls around GUI/view initialization and
`fitAll`, and a crash during GUI interpreter teardown. These are environment
observations, not proof that a generated shape is wrong or that every GUI call
will fail. Use bounded probes; do not repeatedly start the GUI to solve a kernel
geometry problem.

If saved display styling is required, isolate that stage and use the project's
qualified GUI startup/cleanup functions. Close documents and process deferred Qt
deletion before teardown. Diagnose a stall from its logs; do not remove source
or model constraints to get past it. A thumbnail without a valid OpenGL context
is not visual evidence. Avoid adopting forced process exit as a general remedy;
it can conceal unfinished saves or cleanup.

For review images here, `cad/003_FullTank/lib/visual_review.py:shaded` rasterizes
native shape tessellation in software and verifies placements. It can produce
isometric and section views without GUI rendering. Keep review cuts and display
transparency separate from the saved physical model.

Collect the complete selected geometry before rendering views or publishing a
final receipt. A pump-review renderer accidentally nested its three-view pass
inside a 242-occurrence loading loop, issuing 726 renders and repeatedly replacing
incomplete intermediate images. Moving that pass after collection produced three
byte-identical final PNGs on this runtime. A separate output directory preserved
the terminal baseline during verification. The [retained implementation and
comparison](../../../cad/003_FullTank/experiments/drive_chains/engine_pump_receiver_study/assembly_trial02/diagnostics/render_loop/README.md)
document this control-flow failure; image existence alone did not prove completion.

When sharing tessellation by definition, supply the same canonical definition
shape for every occurrence and apply its installed placement separately. A
bottom-stop preview supplied world-posed targets under a shared definition key;
the renderer reused the first mesh and drew repeated parts at that first pose.
Native and STEP geometry were correct. Using identity-frame targets restored both
sides without changing geometry or the camera. Inspect repeated occurrences,
not just one exemplar; a transform calculation alone does not prove that its
cached input belongs to the right frame. The
[retained preview diagnostic](../../../cad/003_FullTank/experiments/drive_chains/transmission_high_brake_support_study/bottom_stops03/diagnostics/render_cache.json)
records this caller-contract failure and the corrected saved-native views.

Sandbox errors have a different cause from CAD errors. A Codex PATH-alias warning
means an optional runtime write failed; verify the actual process exit and tool
operation. A successful `--version` is not proof that a model run can initialize.
Use the controller's restrictive-profile preflight before candidate execution.

## Long native and STEP checks

Keep output and progress under a durable work directory and retain the tool's
job handle. A quiet log or a process absent from another sandbox's PID namespace
does not establish completion; obtain the terminal result before restarting a
job. Distinguish an interrupted check from a geometric failure.

One lower-drive exchange worker on this runtime used about 10.2 GiB RSS.
Copying the required saved shapes and composed occurrence poses, then closing
the large parent document before comparison, preserved all 27 strict results;
closing the document did not immediately imply lower RSS. Serialize similarly
large checks when memory is constrained. The
[retained diagnostic](../../../cad/003_FullTank/experiments/drive_chains/engine_pump_layout_study/lower_drive_trial/checker_memory_revision.json)
records unchanged acceptance predicates and identical completed legacy results.
The preceding process terminations did not establish their cause; do not label
them out-of-memory failures without supporting evidence.

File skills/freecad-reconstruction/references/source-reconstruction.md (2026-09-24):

# Reconstruct from evidence without hiding uncertainty

Use full source figures and their catalogue context. Preserve document, page,
figure/callout, piece mark, configuration applicability, file hash and the literal
wording or value behind a dimension. A cropped shape can lose its leader line or
assembly context. Separate scanned wording, transcription, interpretation and
chosen approximation in the packet.

Search the local figure index by component and mounting name before settling an
uncertain visible form from a general assembly view. In the Liberty gear work,
the timing section left the starting claw ambiguous; the separately indexed
exploded mounting view resolved a broad rim and larger centre opening. Numerical
geometry checks had passed the earlier hypothesis. Preserve that diagnostic and
revise the source comparison before accepting the part. The
[gear reconstruction packet](../../../cad/003_FullTank/packets/P01-engine-driving-gear.md)
records this example and its retained uncertainty.

Before fitting geometry, identify the part, its installed quantity and its
interfaces. Catalogue assembly totals can include subassemblies already counted;
source quantity is not automatically the number of extra installed pieces.
Named source alternatives or later production variants need explicit selection.

Translate explicit assembly and service instructions into geometric requirements
before finalizing estimated interfaces. A shaft can fit its bearing while an
integral gear cannot pass through the bearing housing's receiving lug. Check the
complete moving unit and the stated removal sequence; an offset access opening
does not by itself imply a coaxial path. Preserve a failed envelope as evidence,
and distinguish component fit from a verified installation or removal path. The
[lower distribution-drive study](../../../cad/003_FullTank/packets/P01-engine-lower-distribution.md)
records this constraint and the remaining casing-access work.

When values conflict, retain the original values and calculate the consequences
of each defensible interpretation. For example, an outside diameter and assumed
wire diameter imply a spring inside diameter; a negative clearance is evidence of
a conflict, not authorization to relabel the printed dimension. A geometrically
plausible alternative remains an inference until better evidence supports it.

For source scaling, document datum/axis choices, calibrated dimension, anisotropic
scan distortion where present, pixel-pick uncertainty and held-out dimensions.
Do not transfer a longitudinal side-view calibration to a transverse section.
Reserve unprinted profiles, wall thicknesses, fastener details and fits as named
approximations with useful bounds. Keep physical fit allowance, historical
uncertainty, and numerical Boolean tolerance in separate fields.

Classify each view before comparing geometry: photographic perspective,
orthographic/axonometric, explicitly oblique, or schematic/mixed. An apparent
profile disagreement can be a projection mismatch. Fit a camera only to reviewed
landmark identities and saved CAD coordinates, and retain independent holdouts.
Planar landmarks alone cannot establish an unconstrained general camera. A low
fit residual does not prove either the camera or estimated geometry is correct.

Version image bytes/crop, fitting picks, anchor coordinates, projection assumptions
and solver settings. New unrelated geometry normally reuses that camera. Changed
anchor definitions require locator review; new holdout contradictions trigger
diagnosis before any refit. Keep the old fit and a reason for changing it. Do not
silently turn failed holdouts into fitting points. The MarkVIII source-camera
controls exercise fixed-camera reuse, native-frame binding and perspective depth;
they are synthetic controls, not historical calibration evidence. Mesh previews
still require separate native-solid and interface qualification.

Check the model against the evidence and its neighbors, rather than only against
the same parameter table used to build it. Review silhouettes and sections that
show the disputed feature. Track definition coverage, installed occurrence
coverage and evidence confidence separately. Record what remains unresolved and
which additional evidence could change the chosen geometry.

For MarkVIII work, use `docs/templates/cad-work-packet.md` and the source-linked
stage data. The user-selected priority is the fully populated standard assembly,
including interiors, before pose variants; that priority belongs to this project,
not to a universal FreeCAD rule.

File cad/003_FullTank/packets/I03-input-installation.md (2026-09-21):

# I03 — input cover fasteners and grease feed

This increment extends the [input assembly](I03-input-assembly.md) with four
MX25 stud/nut/cotter sets and the M250 grease-cup installation. It also drills
the corresponding receivers in M264, M250 and all sixteen M254 shim leaves,
and opens a feed through M250 and the M249 spacer into the bearing cavity.
It remains an isolated transmission candidate pending tank integration.

## Source decisions

The [source register](../experiments/drive_chains/transmission_input_installation_sources.json)
retains the literal SNL records and their conflicts. Original SNL77 lists four
MX25 assemblies in the owning M264 cover assembly. SNL240 also gives four in
the catalogue quantity, but its usage note allocates two to M250/M264. This
reconstruction selects four, with an inferred cardinal pattern on the existing
96 mm radius. Neither the section drawing nor this choice resolves the
contradictory usage note.

SNL240 specifies a half-inch stud, 2-17/32 inches long, with one inch of
U.S. Standard thread and 7/8 inch of SAE thread. These convert to diameter
12.7 mm, length 64.29375 mm and thread intervals of 25.4 and 22.225 mm.
The nested nut is printed as one inch; the generic SNL124 nut allocation
instead assigns a three-quarter-inch nut to MX25. Both conflict with the
stud. The modeled half-inch nut is an explicit mechanical interpretation.
Its source record and conflict are retained, but it does **not** claim to
fulfil either conflicting catalogue nut identity. Nut flats, height, slots
and thread clearance are inferred.

Each set includes the printed 3/32 × 1 inch split pin. Its two round-wire
legs are formed outward, preserving a 25.4 mm centreline length under the eye.
The eye and wire section are approximations; exact stock volume, period
manufacture, loads and removal by straightening are not qualified.

SNL78 identifies one No.4 × half-inch grease cup, SNL85 one Q51QD half-inch
beaded 45-degree elbow, and SNL124 one half-inch × 1-3/4 inch close nipple,
all explicitly allocated to M250. The nipple retains the printed 44.45 mm
length. The source does not provide a complete No.4 cup drawing: its hollow
body and screw cap are an inferred two-solid decomposition of **one**
commercial item, with the catalogue identity on the assembly container.

Two modern manufacturer documents support limited dimensional transfers:

- [Wheatland standard-pipe brochure](https://www.wheatland.com/wp-content/uploads/2017/12/Standard-Pipe-Brochure-2.pdf),
  page5: nominal half-inch pipe OD0.840 inch and Schedule40 ID0.622 inch
  give 21.336 and 15.7988 mm. The historical wall schedule is unproven.
- [Anvil Fig1102 submittal](https://www.asc-es.com/resources-and-downloads/1102-45-elbow-submittal),
  page3: the half-inch 45-degree elbow has centre-to-face dimension C=7/8 inch,
  or 22.225 mm. The adjacent A/J table belongs to the 90-degree street elbow
  and is not used. The historic Q51QD casting profile remains inferred.

The downloaded PDFs are retained with hashes. These transfers do not claim
modern construction or ratings for the historical parts.

## Geometry and remaining uncertainty

The [controls](../experiments/drive_chains/transmission_input_installation_controls.json)
separate printed values, transfers and assumptions. The stud starts at
X219.6 mm and ends at X283.89375 mm. Its SAE interval starts at X261.66875,
just before the nut seat at X262.0. The blind receivers are deepened to
X219.4 so the nominal nut base lies within that threaded interval. Threads
are smooth clearance envelopes; the model does not simulate thread contact.
Nut-clearance recesses of 12 mm radius run from X262 to X277 in the housing
barrel. Cotter axes follow the tangent at each stud position, keeping their
eyes and formed tails clear of the barrel. These are inferred joint details.

The grease feed is at X279.0 mm, between the cup backs, 45 degrees above
port. The nipple enters radially and the elbow turns the cup upright.
This location avoids the cardinal stud pattern and opens into the M249
spacer. It is a reconstruction assumption, not a position measured from
SNL Plate23: the fittings lie outside that section plane. The No.4 cup is
44 mm in body diameter with a 48 mm cap; those dimensions are also inferred.

An 8 mm drilled passage continues from the nipple receiver through the spacer
to the open cavity between the opposed cone small ends. This is a connected
geometric route, not a grease-flow calculation or a sealing qualification.
The M249 one-versus-two quantity conflict remains unresolved.

## Qualification

The [combined qualification](../experiments/drive_chains/transmission_input_installation_build/qualification.json)
passes for the [saved candidate](../experiments/drive_chains/transmission_input_installation_build/TransmissionInputInstallationCandidate.FCStd):
**1,303 valid single-solid occurrences**, sixteen new and thirty-six revised,
with 1,251 earlier occurrences retained unchanged. Seven new definitions supply
the added hardware and fittings; two earlier cotter definitions are repaired.
All 653 affected material pairs and 52 raw/bounded STEP comparisons pass with
zero material difference. Twenty-one interfaces are checked in this increment;
573 earlier interface results are retained against unchanged geometry and the
hash-bound parent report.

The [independent checker](../experiments/drive_chains/transmission_input_installation_build/interface_checks.json)
passes 344 checks. These include printed fastener dimensions, thread intervals,
nut seats, both cotter legs/tails, straight-withdrawal obstruction, protected
casting material and a connected grease gauge: diameter2 mm along the main
feed, with diameter1 mm branches passing beneath the cage lips toward both
cone small ends. Deliberately closed housing/spacer passages and a plugged
elbow are detected. This qualifies geometric continuity, not lubricant flow.
Four [local parameter trials](../experiments/drive_chains/transmission_input_installation_build/sensitivity_checks.json)
vary port station and passage diameter using the actual prior housing/spacer;
each checks six affected parts and the radial passage. They are not full-tank
perturbation runs.

All seven final rasters were [visually inspected](../experiments/drive_chains/transmission_input_installation_build/visual_review.json),
including the unchanged SNL23 registration and both repaired pin forms.
Three new progression snapshots preserve the installation cutaway, grease
section and MX25 joint. Twenty standard native files and forty-three earlier
snapshots remain byte-identical. The builder report is an immutable generation
receipt; the combined qualification records completed rendering and review.

An initial construction attempt was rejected before saving a candidate because
the elbow turned the cup horizontal. Reversing the bend in its local plane
restores the intended upright cup. Its exact initial inputs and failure log
remain in the candidate's rejected-trial archive.

The next complete trial found nut/barrel intersections of 0.555–30.596 mm³,
two inward-pointing cotter clashes of 6.785 and 10.059 mm³, and an elbow-bead
intersection of 18.544 mm³ with the housing flange. The nut reliefs and
tangential cotter orientations address the hardware clashes. Moving the
inferred port from X276.5 to X279.0 clears the elbow bead from the flange.
The rejected reports and exact inputs remain preserved.

The swept-torus construction in that trial also failed the two-way STEP
material comparison. Isolated tests reproduced the failure on a single
cotter leg despite matching volume and topology counts. Replacing pipe-shell
arcs with equivalent analytic cylinder/torus segments passed that local
comparison. The candidate uses the analytic construction for both cotter
legs and the elbow; the small-pin check also requires both legs and their
formed tails to remain present after fusion and native reopening.

A stricter independent check then found that the many-piece eye fusion had
dropped one complete leg despite returning a valid single solid. A semicircular
analytic eye with overlapping lead junctions retains both legs; explicit leg
gauges and minimum stock-volume checks now guard that requirement. A focused
audit found the same defect in the older bearing-cap and input-shaft cotter
definitions. This increment repairs those two definitions, affecting sixteen
cap pins and one input-shaft pin, while retaining their source dimensions and
placements. The input-shaft pin still has unspread legs.

The final input-pin STEP comparison had zero raw and bounded material
difference, but the reported maximum tolerance changed from
7.925414398e-6 to 7.925427862e-6 mm. The earlier relative-only guard rejected
that 1.35e-11 mm drift. The validator now declares a separate absolute
1e-10 mm reporting-roundoff allowance; it does not alter either shape's
stored tolerance. The 1e-4 mm native ceiling and bounded material comparison
remain. A negative check rejects a 1e-7 mm increase. The rejected tolerance
receipt is retained so this qualification change is reviewable.

## Reproduce and continue

```sh
python3 cad/003_FullTank/experiments/drive_chains/transmission_input_installation_probe.py --stage cad/003_FullTank
python3 cad/003_FullTank/experiments/drive_chains/check_transmission_input_installation.py --stage cad/003_FullTank
python3 cad/003_FullTank/experiments/drive_chains/check_input_feed_variants.py --stage cad/003_FullTank
python3 cad/003_FullTank/experiments/drive_chains/render_transmission_input_installation.py --stage cad/003_FullTank
```

The builder accepts `--output`; the checker and renderer accept `--candidate`.
The independent rendering receipt binds an immutable builder report.

Input pump attachments, B6205/A7679/A7680/A7682 support components and their
installation remain open. The brake-bearing bushing is **M265**, and its cap
is **M266**. The later MX14 cap-stud work must retain another source conflict:
SNL59's assembly list gives 1-9/16 inches while SNL240 gives 1-11/16 inches.
Case fastening, controls, complete lubrication/mounting and tank integration
remain ahead. This increment is not a completed transmission or full tank.

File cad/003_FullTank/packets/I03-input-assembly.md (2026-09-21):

# I03 — transmission input bearings, housing and coupling

This increment extends the [bevel drive](I03-bevel-drive.md) with the opposed
Timken bearings, M250 housing, M246 coupling, M252 packing disk, M253 felt,
M251 gland, M249 distance piece, MX35/M254 shim packs, M248 washer, MX33 nut,
split pin and four MX22 bolts with eight separate nuts. The integral M247
pinion remains one existing part. Its shaft extension and the M264 input
receiver change to fit the populated assembly.

The input assembly is still partial: cover fasteners, pump attachments,
lubrication, support bracket and detailed retention remain open. It belongs
to the isolated transmission candidate, pending standard-tank integration.

## Source evidence and inventory

The [source register](../experiments/drive_chains/transmission_input_sources.json)
retains the SNL rows, handbook quantity conflict and inspected source hashes.
SNL68/78 specify a 69.85 mm cone bore, 54.229 mm cone width, 149.225 mm cup
outside diameter and 44.45 mm cup width. The current
[Timken 6454/6420 listing](https://cad.timken.com/item/tapered-roller-bearings-ts-tapered-single-/tapered-roller-bearings-ts-tapered-single-imperi-2/6454-6420/)
corroborates those four dimensions. Its assembled width of 53.975 mm is used
as a provisional transfer; agreement does not prove unchanged historical
internal construction. Timken's [bearing design reference](https://www.timken.com/resources/tapered-roller-bearing-catalog/)
supports the common-apex construction method, not our inferred race angles,
roller count or cage dimensions.

Each bearing has a cup and a cone subassembly; the cone has an inner race,
a perforated conical cage and sixteen linked tapered rollers. The canonical
commercial identities belong to the assembly containers and cup leaf.
Embedded SNL18/112 aliases are recorded explicitly. Thirty-eight internal
solids represent two commercial bearings, rather than thirty-eight catalogue
bearings. Both bearings reuse the same four definitions.

SNL27 expressly gives two 3/8 inch plain nuts for each MX22 bolt. These are
modeled separately; lock washers are not substituted. The SNL's thirteen
MX35 and sixteen M254 shims are marked “as required.” This reconstruction
selects those nominal counts with assumed 0.1 and 0.125 mm leaf thicknesses.
SNL215 supplies the 3/16 × 2-1/2 inch split pin; its legs remain unspread.
Threads are plain diameter envelopes and the nut/head sizes are inferred.

Two inventory conflicts remain explicit:

- SNL112 lists one M249 distance piece, while SNL134 and HB205 list two.
  One outer-cup spacer is provisionally installed from the assembly list and
  section interpretation. The second catalogue allocation is unresolved.
- Original SNL240 prints a one-inch nut for a half-inch MX25 stud, and its
  global quantity differs from the stated housing-joint allocation. These
  cover fasteners remain pending; the modeled receivers do not resolve that
  source conflict.

## Geometry and visual registration

The [controls](../experiments/drive_chains/transmission_input_controls.json)
separate printed dimensions, the modern width transfer and reconstruction
assumptions. X increases from the bevel centre toward the coupling. The
inboard cone seats at X203 mm; the small cone faces are X257.229 and
X297.229 mm. The outboard cone seats against the coupling at X351.458 mm.
The spacer and thirteen separate shims locate the cup backs. Sixteen M254
leaves occupy the cover/flange joint at X248–250 mm.

The packing cavity and gland are sized to let the source-sized cups pass
through the housing's open end. The packing disk has a narrow annular nose
against the outboard cup, and an inward flange clear of the rotating cone.
The felt contacts the coupling sleeve. The shaft thread starts at X466 mm
beneath the washer; the nut seats at X470 mm and the shaft/flange ends are
X490 mm. Coupling bolt pattern, casting sections, splines, fits, grease
passages and sealing details are not original manufacturing dimensions.

The [Plate23 calibration](../experiments/drive_chains/transmission_input_calibration.json)
uses the cup's 149.225 mm outside diameter over a visually picked 162 pixels.
The resulting 0.921142 mm/pixel scale has independent axial-width residuals
of +4.724 mm for the cone and +7.134 mm for the cup. Those discrepancies remain
visible; the source raster is not stretched to match the model. Plate22's
existing hub-based scale is retained for a separate comparison.
The cup-diameter pick midpoint is also seven pixels above the selected bevel
centre, a 6.448 mm apparent axis offset. The model retains a common mechanical
axis; that scan/illustration discrepancy is not silently absorbed into a
misaligned bearing placement. The printed-pitch pinion remains visibly smaller
than the illustrated profile in Plate23, as in the previous bevel review.

**Correction to the preceding review:** Plate22 shows the coupling detached
beside the principal section. That section's endpoint is therefore not the
complete assembled shaft endpoint. The earlier statement that the shaft
was necessarily too long is withdrawn. Plate23 is used for the complete
axial span, with its own scale uncertainty. The earlier 32.113 mm bevel/output
registration disagreement also remains unresolved.

## Verification and rejected trials

The initial bearing trial found a 148.096 mm³ cage/rib intersection. The
assumed large rib radius was reduced from 60 to 59 mm, and the cage pockets
were extended axially so the roller end faces have clearance. The first
complete assembly trial found a 3,859.497 mm³ washer/spline intersection.
Separating the thread-start datum from the nut seat corrects that defect.

The independent checker's first pass also exposed two measurement mistakes:
the cached display mesh gave a slightly undersized cup bounding box, and each
cage pocket had two conical wall patches. The corrected checks measure the
saved analytic cylinder radius and count unique inclined pocket axes. The
CAD geometry was unchanged by those checker corrections.

The saved candidate reopens with **1,287 valid single-solid leaves**: 88 new,
two revised and 1,197 retained unchanged. All 749 affected material pairs,
578 specified interfaces and 90 native/STEP material comparisons pass. Both
raw and bounded exchange comparisons have zero material difference; stored
tolerances are not inflated. Further qualification results and inspected
raster hashes are recorded in the build reports. Geometry checks include
native reopen, all affected material pairs
against the candidate and standard physical context, seats/clearances,
two-way STEP material comparisons, printed bearing envelopes, shared
definitions, common-apex race surfaces, cup insertion and shaft passage
gauges, and deliberate obstructed-entry/displaced-STEP negatives. This does
not qualify operating preload, contact stress, sealing, manufactured fits,
formed cotter retention or the complete transmission installation sequence.

The [independent checker](../experiments/drive_chains/transmission_input_build/interface_checks.json)
passes 181 checks. The [visual review](../experiments/drive_chains/transmission_input_build/visual_review.json)
records all six inspected images, including the
[Plate23 overlay](../experiments/drive_chains/transmission_input_build/source_review/input_plate23_overlay.png).
The [saved native candidate](../experiments/drive_chains/transmission_input_build/TransmissionInputCandidate.FCStd)
retains all accepted pinion spline surfaces and material outside the shaft
extension region. Twenty standard native files and forty previous snapshots
remain byte-identical; three new progression images preserve this increment.

## Reproduce and continue

```sh
python3 cad/003_FullTank/experiments/drive_chains/transmission_input_probe.py --stage cad/003_FullTank
python3 cad/003_FullTank/experiments/drive_chains/render_transmission_input_review.py --stage cad/003_FullTank
python3 cad/003_FullTank/experiments/drive_chains/check_transmission_input.py --stage cad/003_FullTank
```

Use `--output` on the builder and `--candidate` on renderer/checker for trials.
Next resolve the M249/MX25 allocations and finish the housing installation,
then the M265/M266 brake-bearing joint, case fastening, controls, lubrication,
mounting and standard-tank integration. The complete-tank objective remains
active; this increment is not a finished transmission or tank.

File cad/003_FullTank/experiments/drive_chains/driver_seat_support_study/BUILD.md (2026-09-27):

# Connected seat support prototype — 27 September 2026

The [saved native](trial01/ControlRebuildTrial.FCStd) contains **281 occurrences /
97 definitions**, adding 54 physical parts to the preceding seat study. Four
stays now connect the seat bearings to the support plates; separate M788 angles
connect the plates to the two real floor planes. This is a locally checked static
assembly. Historical position, adjusting/locking details and full-tank integration
remain open.

- [Isometric](trial01/visual01/isometric.png).
- [Connections with upholstery hidden](trial01/visual01/connections.png).
- [Fixed source-section comparison](trial01/visual01/source_section.png).
- [Installed STEP additions and revisions](trial01/exchange01/RebuiltControlAdditionsInstalled.step).
- [Reviewed support sources](README.md).

## Geometry and source stock

| Component or interface | Installed construction |
|---|---|
| Four SH289E bearings | Earlier 16.3 mm estimate replaced by a 19.3 mm through bore for the printed 19.05 mm bolts. Flange, rivet holes and other external material preserved. |
| Two front SH289B / two rear SH289D stays | Two shared definitions, placed by rigid transforms. Estimated dogleg strips with 6.35 mm projected transverse stock, 28 mm webs and 18/20 mm end-pad radii. |
| Four upper stay joints | Full 19.05 × 60.325 mm bolts, plain nuts and lock washers. Actual 36.35 mm bearing/stay grip; 1.75 mm bolt protrusion. |
| Four lower stay joints | Full 12.7 × 34.925 mm bolts, plain nuts and locks; actual stay/plate receiving bores and seats. |
| M786/M787 side plates | Shaft bores and frames retained; provisional outlines extended to lower stay joints. Estimated folded feet removed from these definitions. |
| Two separate M788 angles | 6.35 mm stock, 55 mm vertical leaves and a sharp longitudinal bend following the two floor planes. Form and mounting allocation remain estimates. |
| Eight plate-to-angle joints | Existing complete 12.7 × 31.75 mm bolt/nut/lock sets relocated to the vertical receiving leaves. |
| Eight angle-to-floor joints | New complete 12.7 × 41.275 mm bolt/nut/lock sets reuse the actual floor seating frames and holes. |

The upper bolt application still literally names A/B stays, whereas the stay list
and lower bolts name B/D. That printed-source conflict remains explicit. Bolt
lengths are interpreted under the head; thread envelopes, head/nut exteriors,
clearances and compressed lock shapes remain approximations. Nothing is shortened
to avoid an intersection. The dogleg web stock is measured in projected Y, not
claimed as constant-normal rolled strip thickness.

The nominal lower joints use the inherited conditional section picks. A second
complete build raises those four lower joints by 5 mm, testing regenerated stays,
plate outlines and bolt frames without moving the seat or shafts. Parameters
require regeneration; no live expression behavior is claimed.

## Verification and visual interpretation

Both builds pass **607 independent saved-material/interface checks** and **96
strict STEP comparisons**. The nominal context audit checks 269 nearby pairs;
the raised-joint variation checks 267. Both have zero intersections, with no
mating exemptions. Audits include the retained operating controls and physical
standard context. Head, lock, nut, receiver, plate/angle and angle/floor contacts
are checked as actual material interfaces. Negative controls reject the old
undersized receiver and lifted full-stock bolts.

A fresh nominal build reproduces **291 archived BReps and 15,059 stable persistent
properties**, including all definitions, frames and metadata. Unchanged inherited
geometry remains exact; the three revised definitions and 24 relocated fastener
occurrences are declared explicitly.

The inspected source overlay still has a flatter/lower cushion and differing
back curve. Stay endpoints agree by construction. Side-plate outline, separate
angle assignment, absolute shaft/seat placement and source control state remain
unproven. The source image must also be read with its foreground objects:
[original SNL35 identifies Plate 2 callout 56 as a gun-tool box](source_visibility01/source_review.json).
This raises an identification/occlusion question about earlier assumed shaft
landmarks; it does not itself prove the current shaft height or explain the
separate SNL6 grip discrepancies. No camera refit is performed.

The snapshot is retained as a separate diagnostic study. Accepted development
remains 3,582 occurrences / 635 definitions / 442 groups, and accepted image
progression remains 308. The standard tank011 model is unchanged.

## Reproduce and continue

Use absolute worker and output paths through the existing headless launcher.
Run `build_driver_seat_supports.py --output NEW_PATH --lower-z-offset 0`, extract
with `pump_integration_worker.py`, then run `check_driver_seat_supports.py`,
`check_driver_seat_context.py` and `exchange_driver_seat_v2.py`. Repeat at offset
5 mm. Compare a fresh nominal build using `check_control_rebuild_reproduction.py`.
`render_driver_seat_supports.py` generates the inspected views. Verify the frozen
study with `verify_driver_seat_support_study.py`.

Next positively identify the SNL2 shaft/lever landmarks and occluding tool-box
outline, compare them with SNL6 and HB6, and resolve the absolute driver layout
before promoting a coupled bow/driver/seat revision. Complete the remaining
adjustment/locking fittings, including the separately listed SH291C, as evidence
allows. Mechanical connectivity alone does not settle these remaining details.

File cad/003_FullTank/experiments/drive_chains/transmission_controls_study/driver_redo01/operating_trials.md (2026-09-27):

# Complete operating handles and pivot joints

`operating02` builds M738B port and M738A starboard handles, M747/M746 fulcrums,
and two complete M776/M768/cotter joints. Ten additions use seven definitions.
Four existing upper selector arms/jaws change; all journal, oilway and lower
linkage material outside the explicit upper-arm edit envelope is preserved.
Every inherited occurrence frame remains fixed.

The source packet is [operating_source_review02.json](operating_source_review02.json).
The printed 37-inch handle length is provisionally interpreted as the canonical
radial extent from the lower eye extremity to grip end, 939.8 mm. It is not
asserted to be a printed pivot-to-tip or developed-centerline datum.

## Initial interference and revision

`operating01` is retained with its eight failed interference pairs. Both handles
met the straight selector stems and front hull plate; each cotter eye lead also
met its bolt by 0.06157 mm³. The original builders and source controls remain
available, including copies in `operating_diagnostics01/first_interface`.

The second trial uses a 50 mm radial pivot drop and 78 mm tangential fulcrum-ear
offset. The handle heel wraps around the shaft, rises into the selector plane,
and has a 20 mm upper return. The low-selector upper arms move 45 mm outward,
consistent with the splayed form in the source plan. Their actual C mouths now
receive the handles, with 0.45 mm fore/aft face clearance. These unprinted forms,
stocks, positions, bend details and the selected eight-degree lateral angle are
reconstruction estimates, not a source tracing or motion qualification.

The specific M776 assembly in the original SNL23 specifies a 3/16 x 1-inch split
pin. The generic SNL141 1-1/2-inch row also names M776. The shorter, specifically
listed pin is selected here; the conflict remains open. Its split plane lies
through the crown nut's axial slots. Moving the inferred near-eye stand-off from
0.2 to 0.75 mm removes the small lead collision without changing the source leg
length or original bore clearance. Measured cylinder/toroid/tail centerlines are
23.175 + 0.872665 + 1.352335 = **25.4 mm** per leg. Eye/junction convention and
formed-wire details remain estimates. Full material and strict STEP checks pass.

## Mechanical evidence and limits

Nominal 12.7 mm and variant 13 mm handle stock each pass **419 local checks,
53 context pairs without exemptions and 25 strict native/STEP comparisons**.
A fresh prototype rebuild reproduces 126 BReps and 9,116 persistent properties.
The actual head and nut bearing area is 759.591208 mm² at each joint. Both low
selector drive faces engage 410.393925 mm² on port and 388.457659 mm² on starboard
when the nominal clearance is taken up. The high selectors clear by 3.933679 mm.
The complete handles clear the front hull by 14.082184 mm.

Displaced checks demonstrate loss of seating, over-travel interference, cotter
withdrawal resistance and blocked crown-nut rotation. This establishes only the
selected local static geometry. Trigger/pawl parts, separate gates/stops, braking
interconnection, springs, spacing, reverse controls and complete seat support
remain unbuilt or unfinished. No full operating cycle or hand-space claim is made.

## Source discrepancy must stay visible

Six saved views were inspected, including unchanged SNL6 plan and HB113 side
registrations. Grip residuals are **47.16/48.59 px in plan and 49.41 px in side**,
well beyond the 5 px pick allowance. The pivot residual is 4.92 px. The retained
high-rod eye discrepancy is still 13.53 px. These are not passing historical-fit
results, and neither source registration is refitted.

[Source diagnosis](operating02/source_comparison_diagnosis.json) shows why a
simple pose adjustment is insufficient. The inferred cap-to-current-pivot reach
is 1013.62/1015.82 mm, versus the actual 922.49 mm. The source views disagree in
fore/aft coordinate by 35.18/38.73 mm. Literal transfer of the side cap to the
current driver station puts it 44.59 mm beyond the current hull front plane.
The source side cap radius from the main shaft is 940.88 mm, close to the printed
939.8 mm. That raises a plausible alternative length datum; it does not prove it.

The ambiguous printed datum, source feature identities and local scale, depicted
configuration, and absolute driver/hull placement require reconciliation. Keep
this as an explicit evidence decision. Do not stretch the stock, move whole
subassemblies or refit cameras merely to make the overlay agree. Current geometry
is a mechanically checked reconstruction approximation, not a historically
qualified installation. This evidence review should precede fixing the trigger
and grip fittings to the current upper blade.

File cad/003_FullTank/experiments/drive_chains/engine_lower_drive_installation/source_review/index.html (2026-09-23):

# Lower-drive receiving-case candidate

Source views guide form; no camera registration or measured casting profile is claimed. The 184 mm pump-axis drop remains estimated. Pump internals, mounting hardware and historical dimensional reconciliation remain pending. Display cuts do not modify the saved model.

## figure_096_original.png / underside

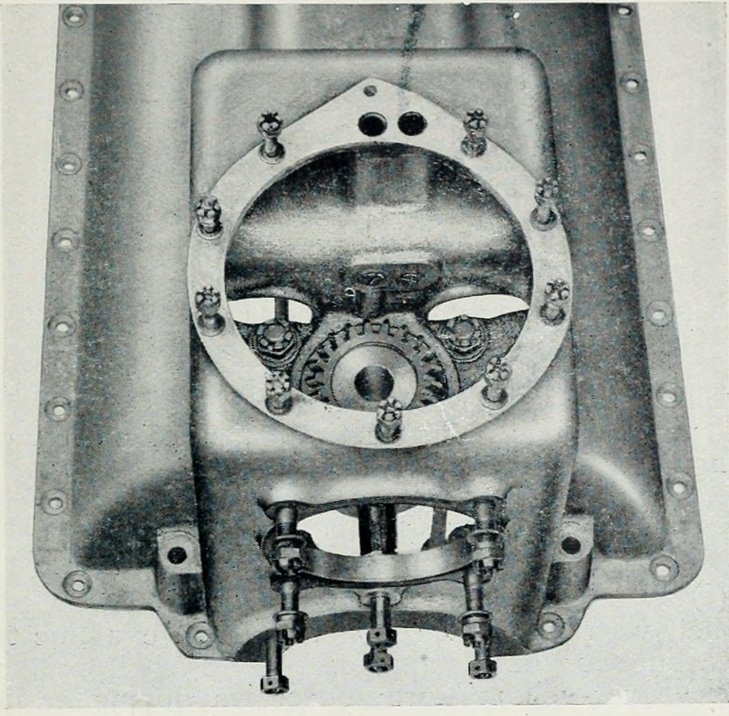
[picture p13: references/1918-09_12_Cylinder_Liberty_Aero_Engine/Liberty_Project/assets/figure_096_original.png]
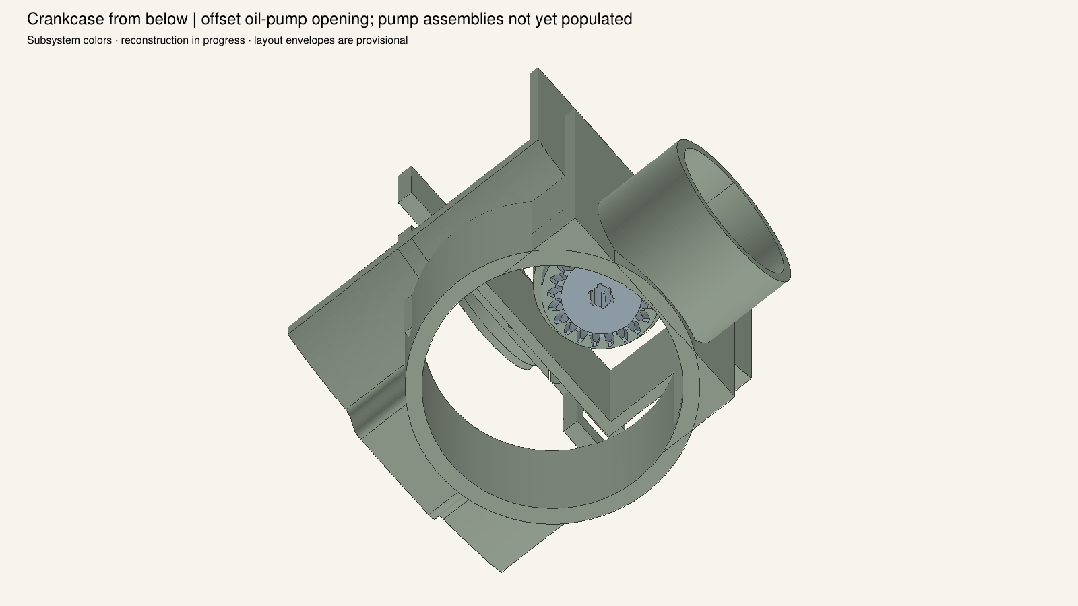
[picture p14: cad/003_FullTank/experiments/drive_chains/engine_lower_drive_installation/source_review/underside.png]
 

## figure_107_original.png / longitudinal

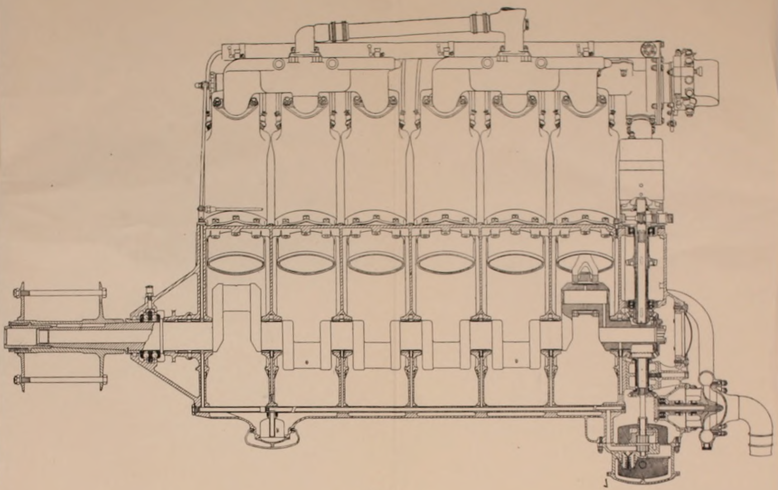
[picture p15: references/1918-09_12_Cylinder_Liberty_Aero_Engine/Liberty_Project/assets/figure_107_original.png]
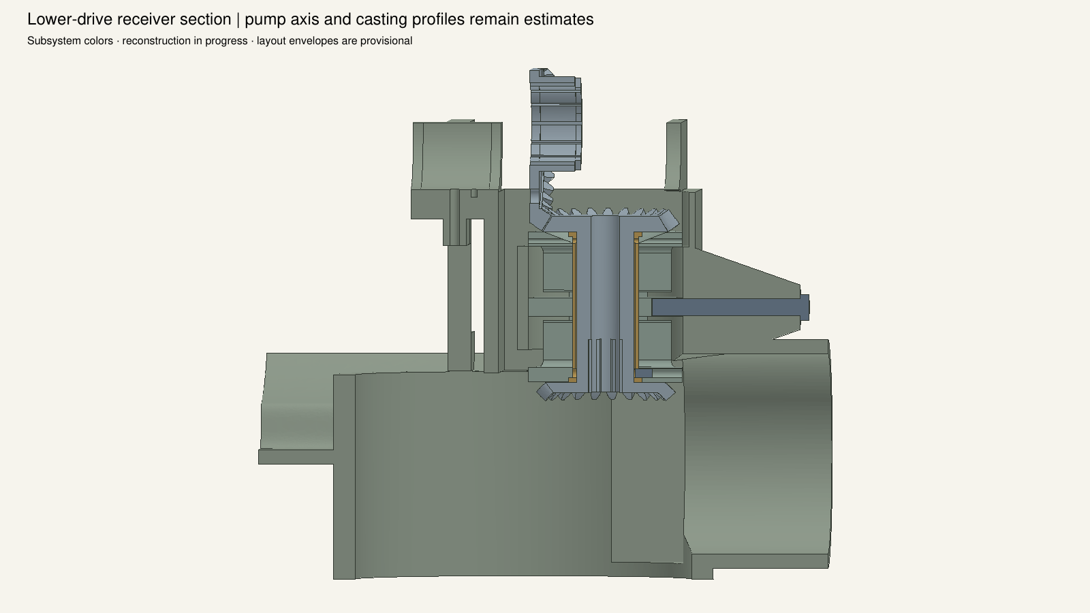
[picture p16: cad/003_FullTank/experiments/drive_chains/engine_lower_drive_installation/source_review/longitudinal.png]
 

## p291-geometry.png / screw_support

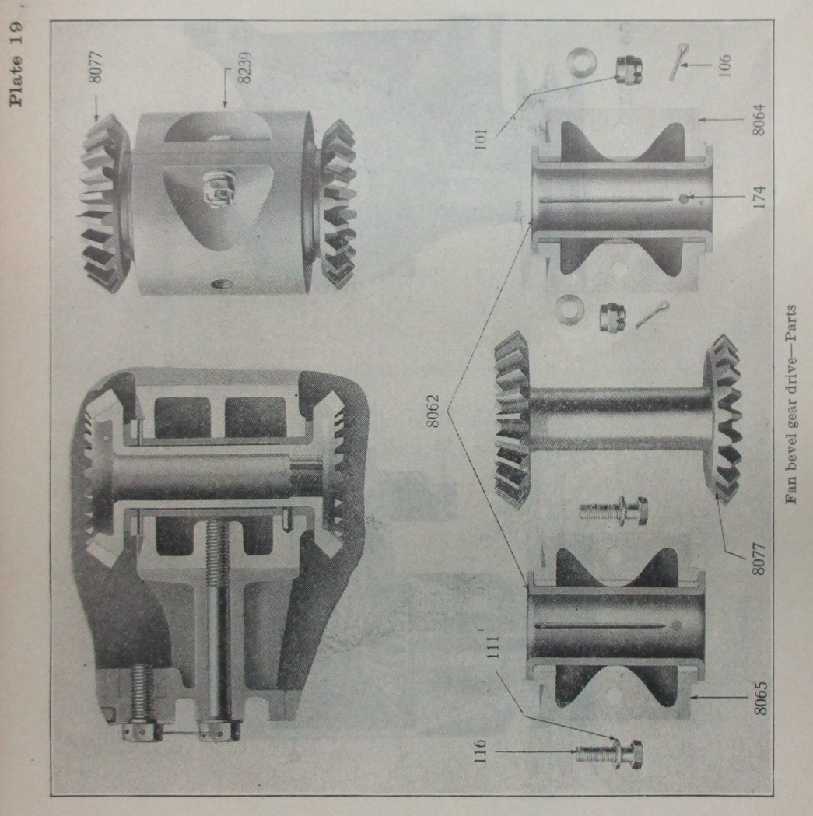
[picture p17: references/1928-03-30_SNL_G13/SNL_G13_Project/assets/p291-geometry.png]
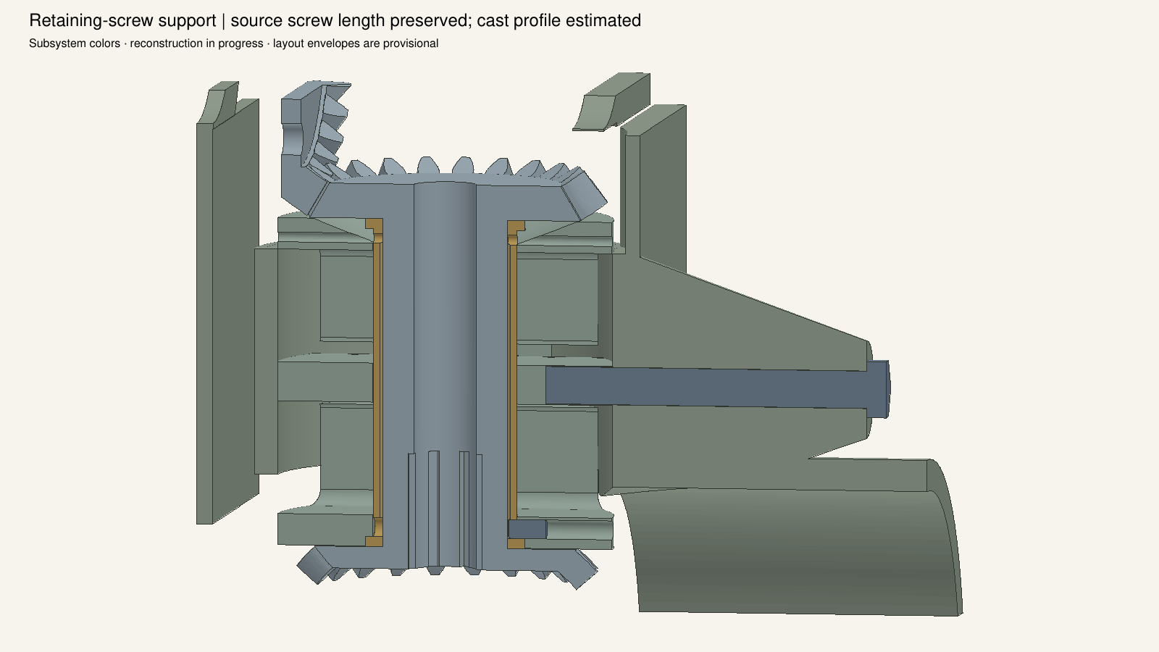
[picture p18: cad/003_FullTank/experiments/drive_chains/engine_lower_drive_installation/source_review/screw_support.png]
 

## p289-geometry.png / pump_interface

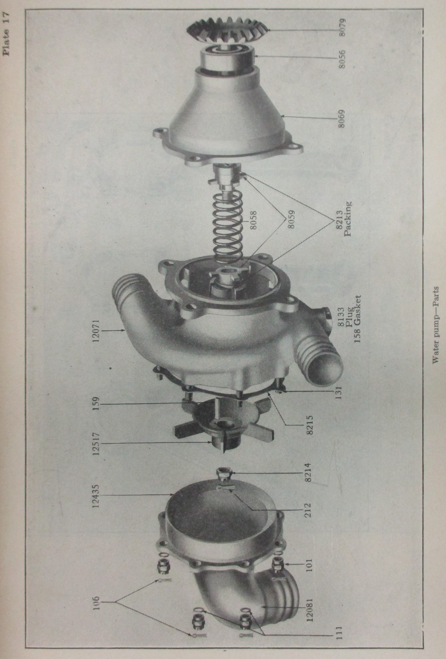
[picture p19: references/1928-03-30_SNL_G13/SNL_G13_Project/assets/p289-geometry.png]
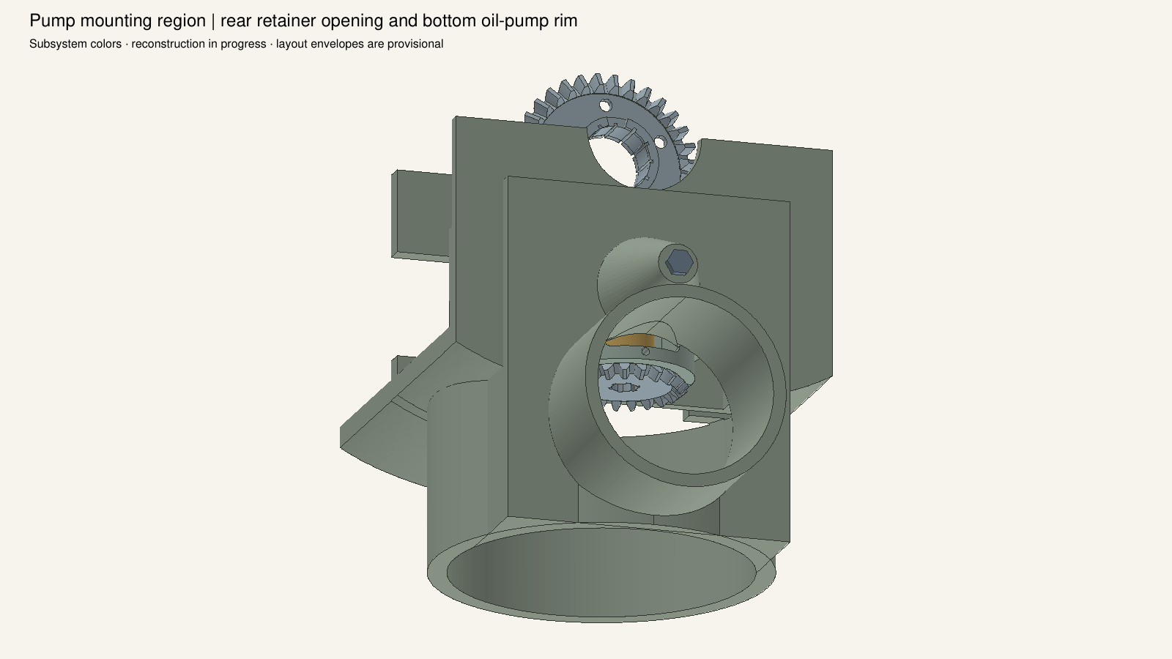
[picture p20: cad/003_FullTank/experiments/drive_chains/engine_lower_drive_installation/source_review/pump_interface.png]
 

## isometric

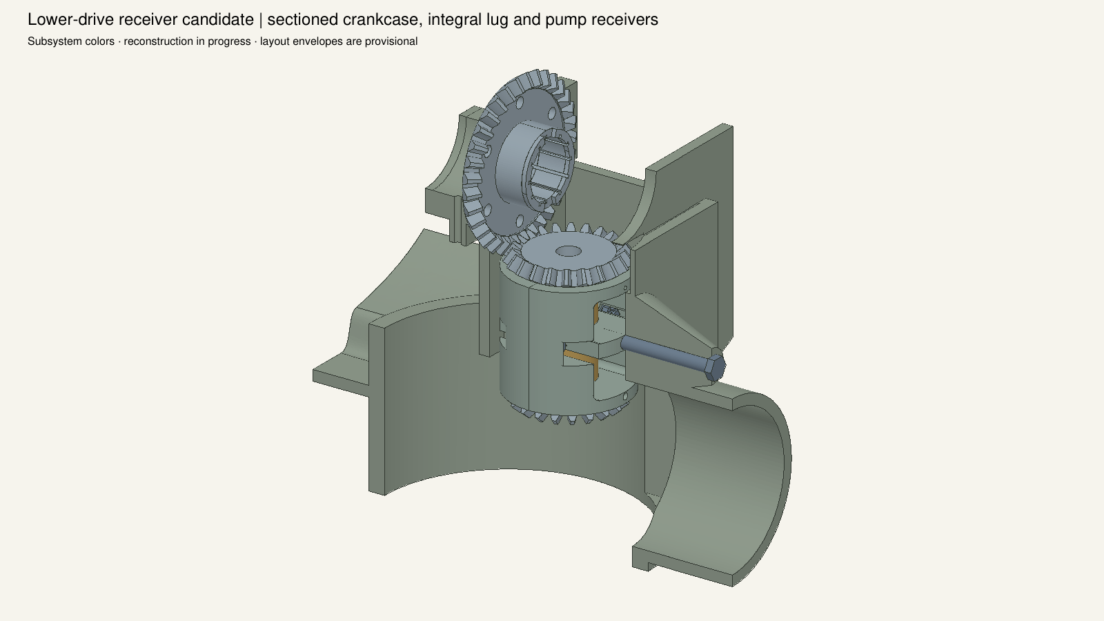
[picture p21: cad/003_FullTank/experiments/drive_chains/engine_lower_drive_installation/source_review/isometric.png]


## longitudinal



## underside



## case_only

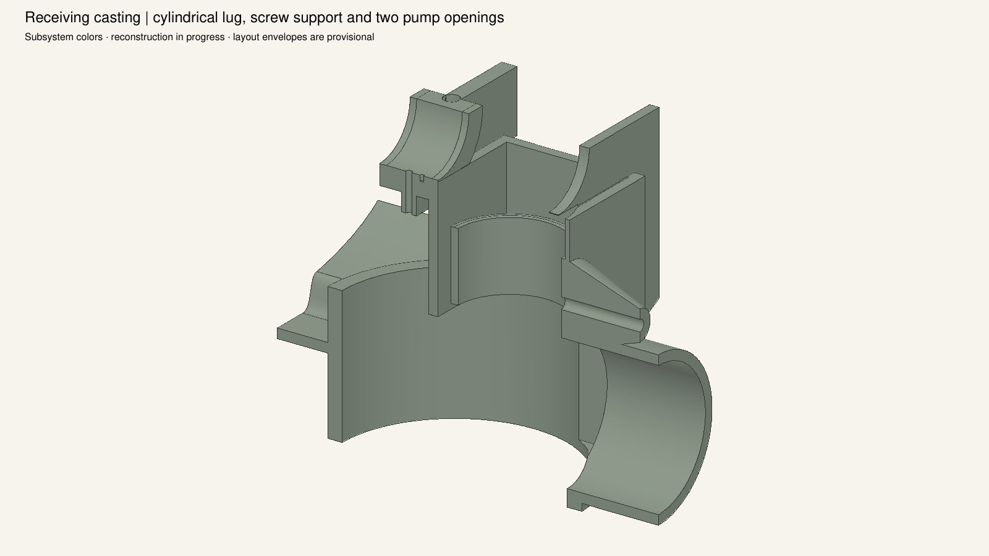
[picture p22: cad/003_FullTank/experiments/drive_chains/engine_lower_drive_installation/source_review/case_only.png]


## screw_support



## pump_interface



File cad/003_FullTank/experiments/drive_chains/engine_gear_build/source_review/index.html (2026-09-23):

# Liberty driving gear development

Source identities, counts and conditional dimensions are retained separately from estimated profiles. HB199 printed3/32in grip conflicts with the installed stack and has not been silently corrected. Claw/spline counts and lock-wire route remain unverified estimates. Mating pinions, final shim stack and backlash remain pending. Cameras are not registered; display cuts do not alter the saved physical model.

## Liberty figure 86 / gear_joint

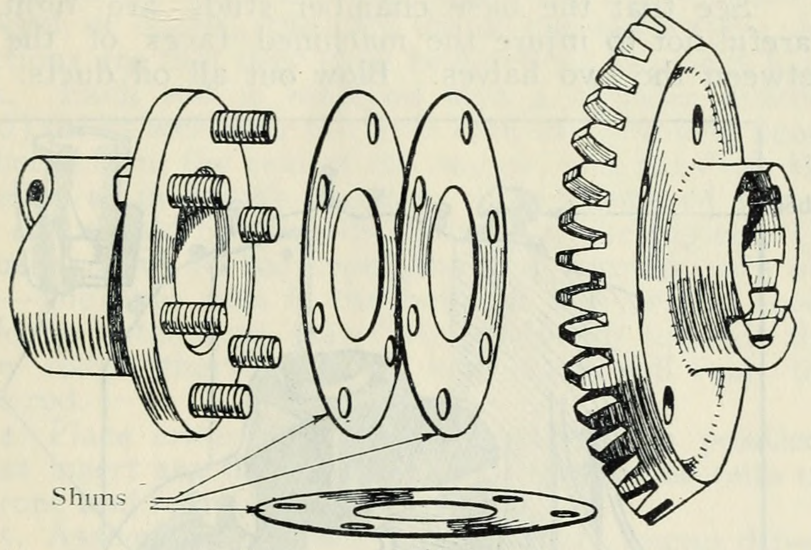
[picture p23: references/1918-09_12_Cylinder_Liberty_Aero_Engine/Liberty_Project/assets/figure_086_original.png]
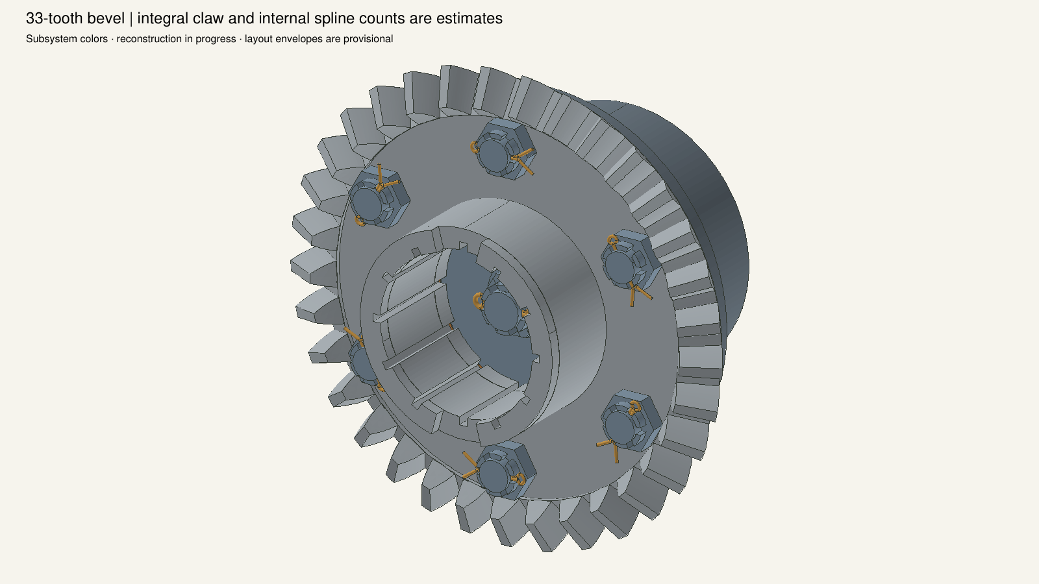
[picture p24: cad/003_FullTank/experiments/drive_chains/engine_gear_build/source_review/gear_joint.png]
 

## Liberty figure 22 / gear_joint

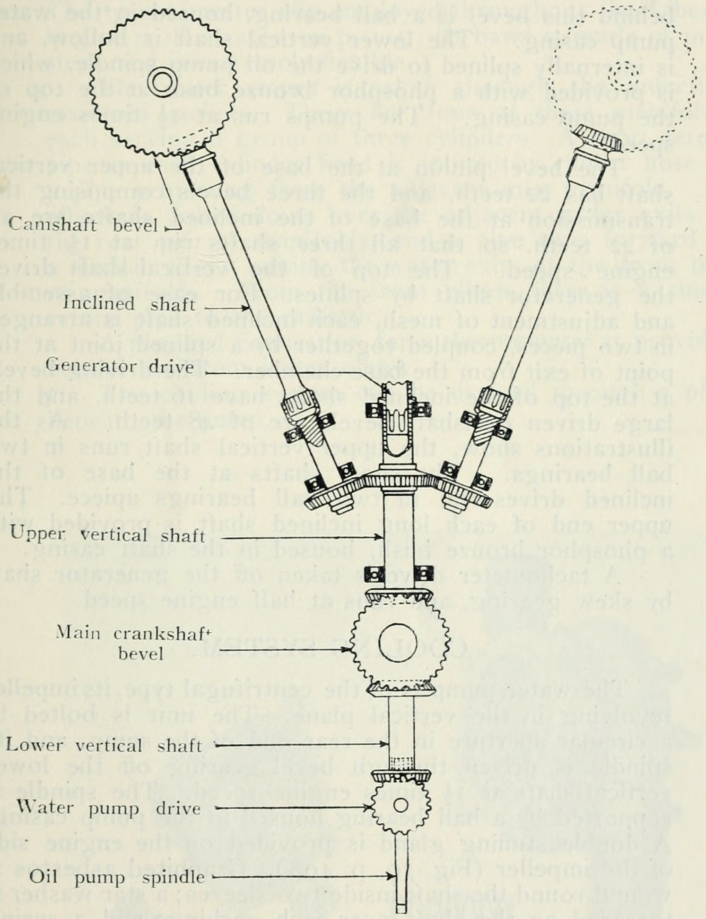
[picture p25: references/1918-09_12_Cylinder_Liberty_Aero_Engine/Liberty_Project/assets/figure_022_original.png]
 

## Liberty figure 93 / gear_end

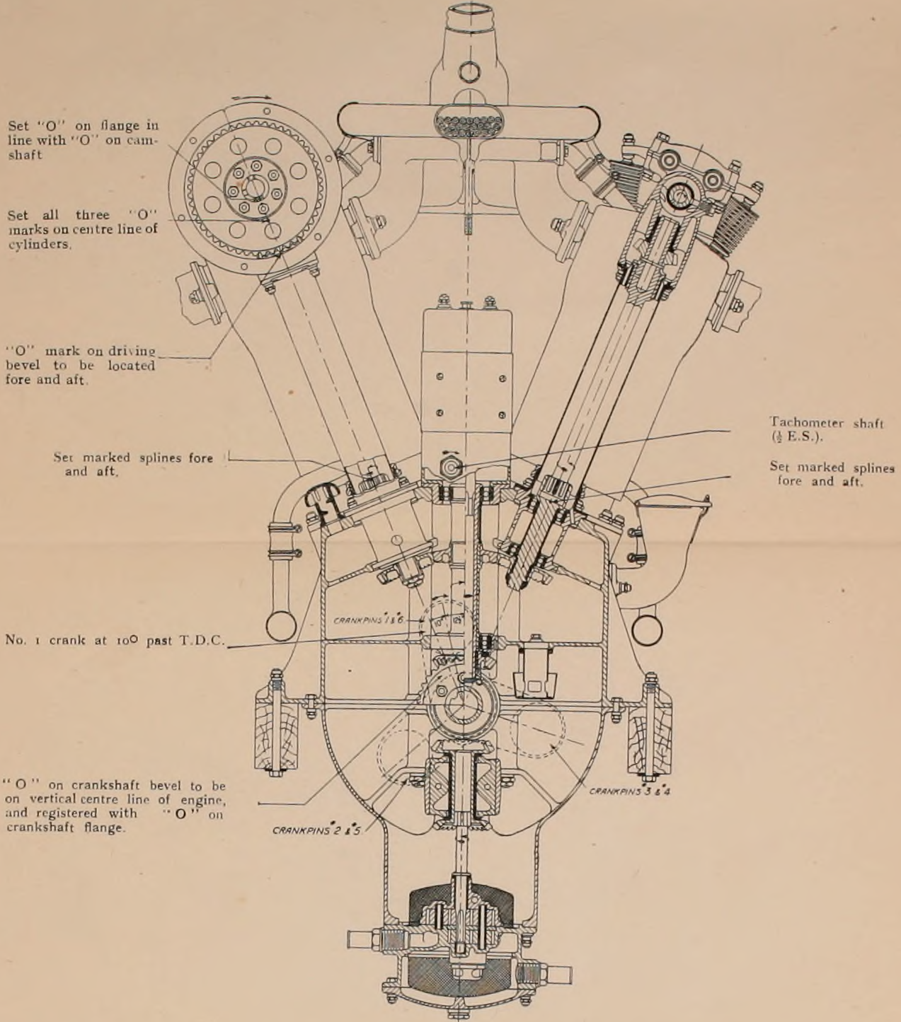
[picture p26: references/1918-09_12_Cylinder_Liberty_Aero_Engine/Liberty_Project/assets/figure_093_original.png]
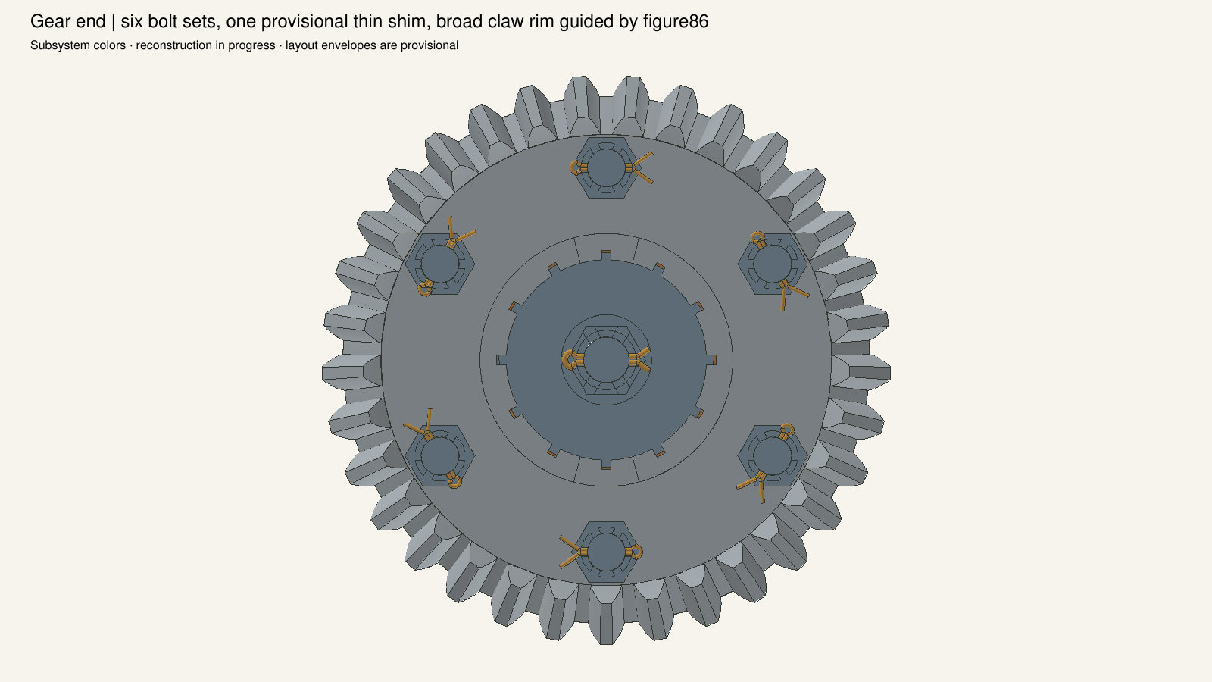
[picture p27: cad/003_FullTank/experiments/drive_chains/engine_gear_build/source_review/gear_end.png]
 

## Liberty figure 107 / isometric

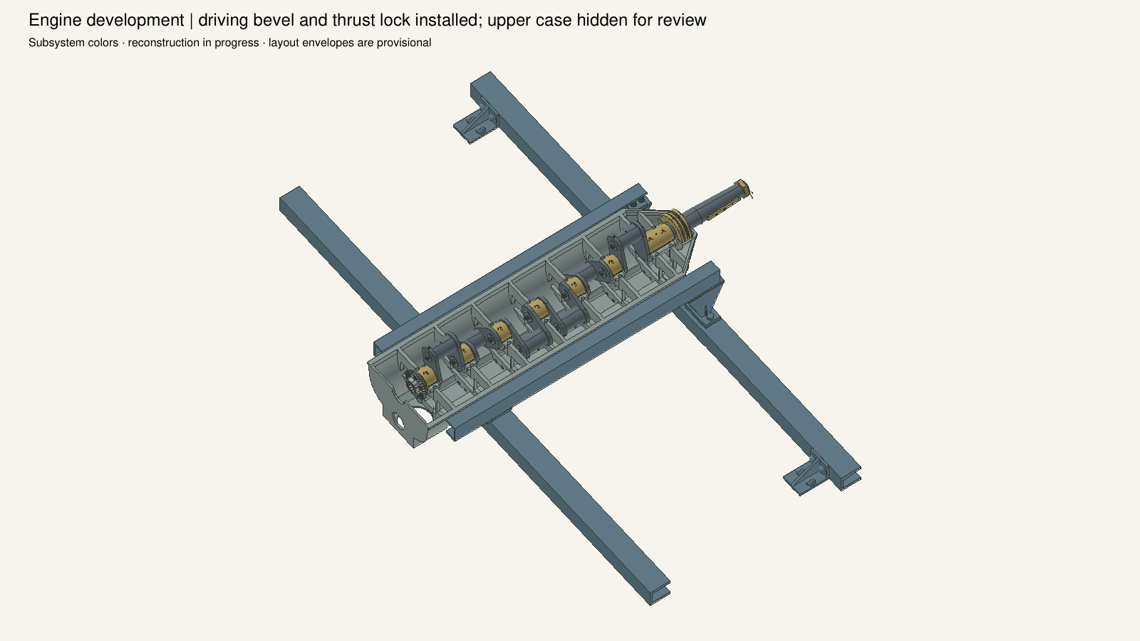
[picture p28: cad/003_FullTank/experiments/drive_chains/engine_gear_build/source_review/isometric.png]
 

Original SNL page 23

Original SNL page 99

Original SNL page 202

Original SNL page 212

Original SNL page 217

Original handbook scan 48

Original handbook scan 100

## isometric



## gear_joint



## gear_end



## gear_section

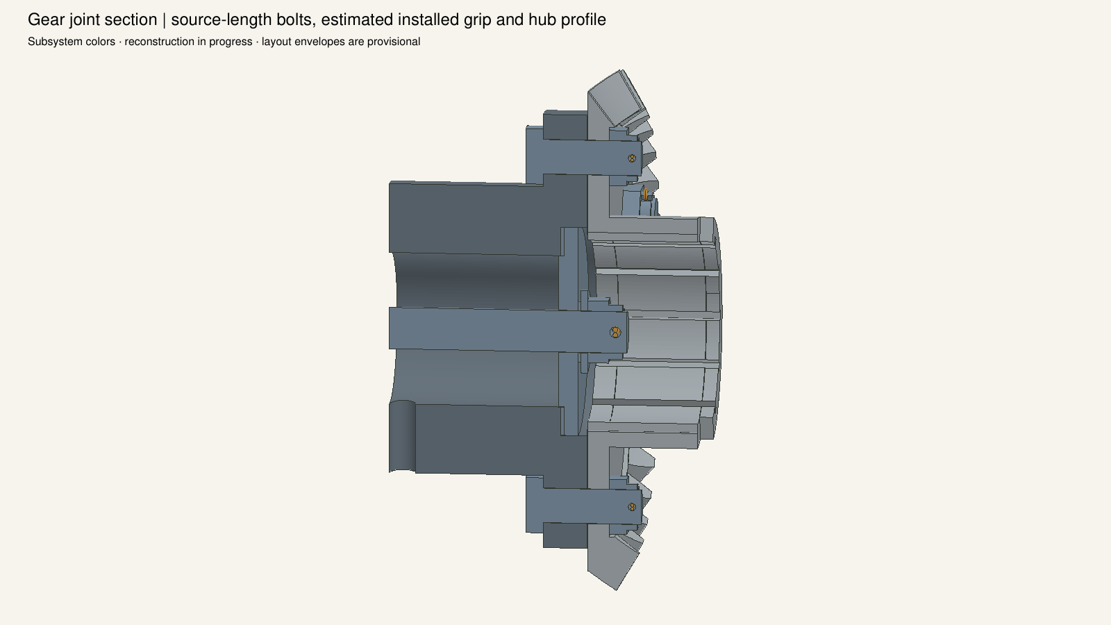
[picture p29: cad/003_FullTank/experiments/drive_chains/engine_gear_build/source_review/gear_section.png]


## thrust_lock

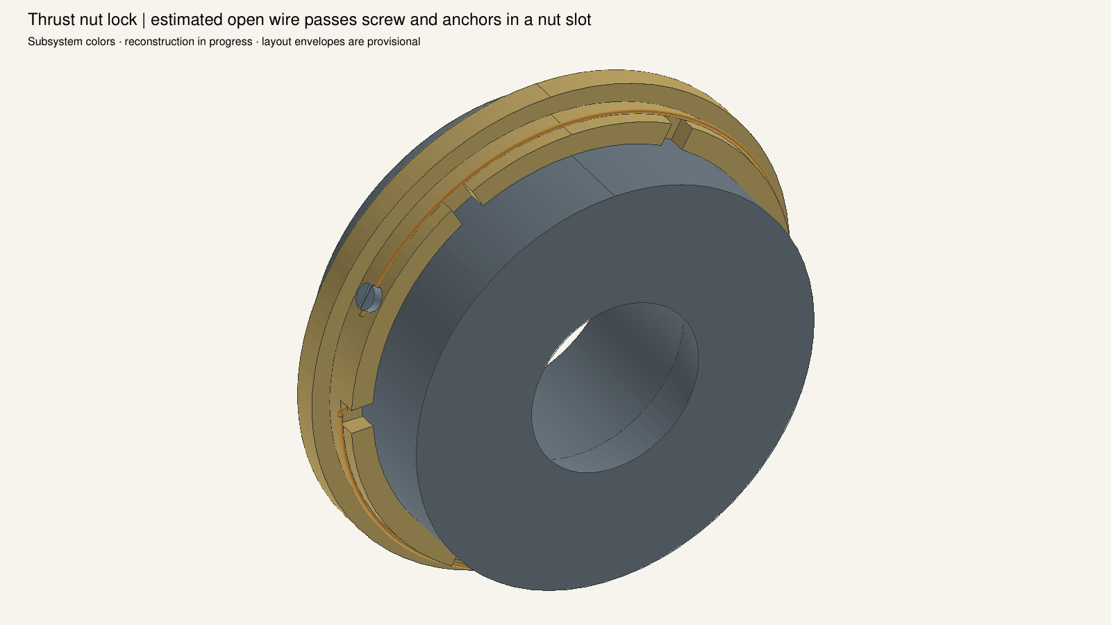
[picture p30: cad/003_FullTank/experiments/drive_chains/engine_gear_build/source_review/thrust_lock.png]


## thrust_lock_section

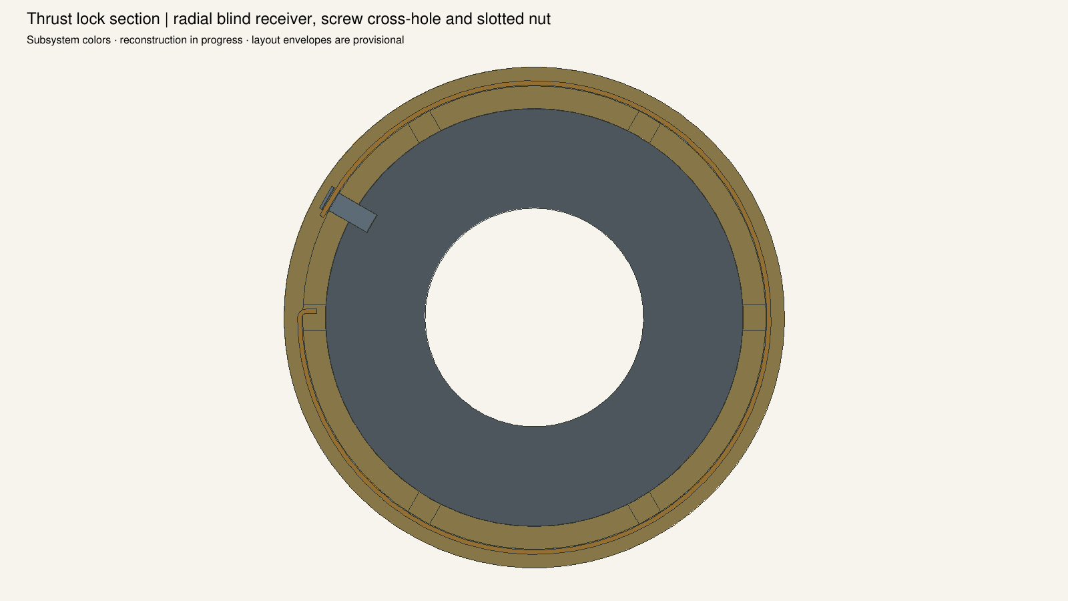
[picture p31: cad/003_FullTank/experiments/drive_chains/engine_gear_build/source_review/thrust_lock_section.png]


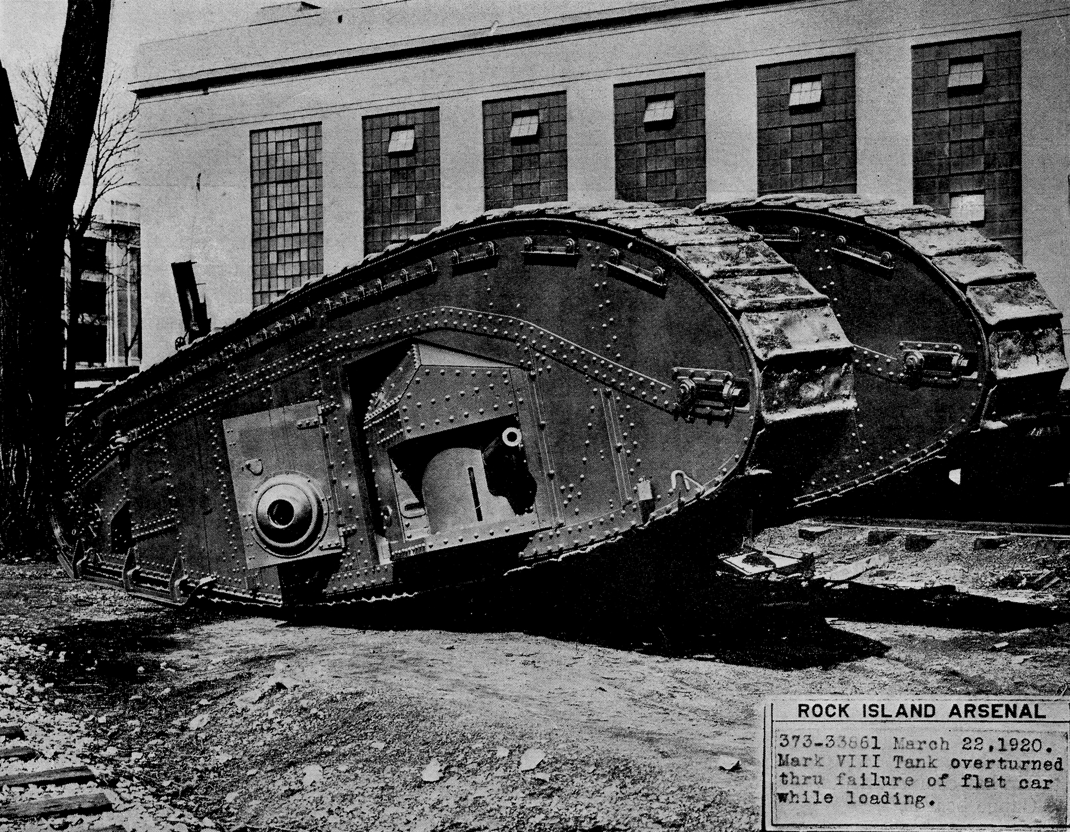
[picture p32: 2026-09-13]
references/1920-07_Manufacture_of_Mark_VIII_Tanks/Article_Project/assets/loading_accident.png

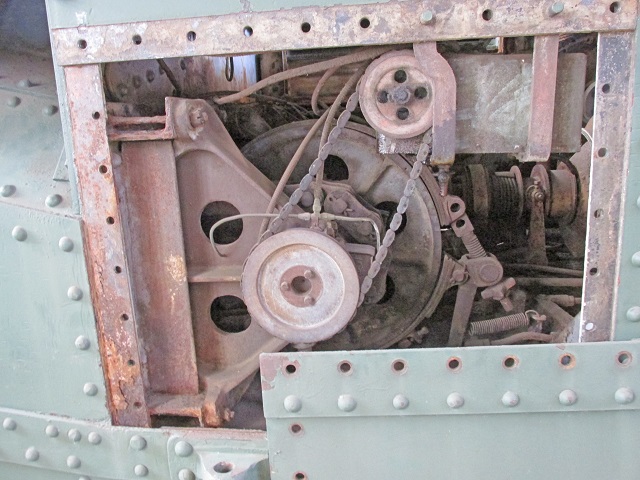
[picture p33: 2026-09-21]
cad/003_FullTank/experiments/drive_chains/transmission_case_mount_trial_build/source_review/photos/mkviiibrake.jpg

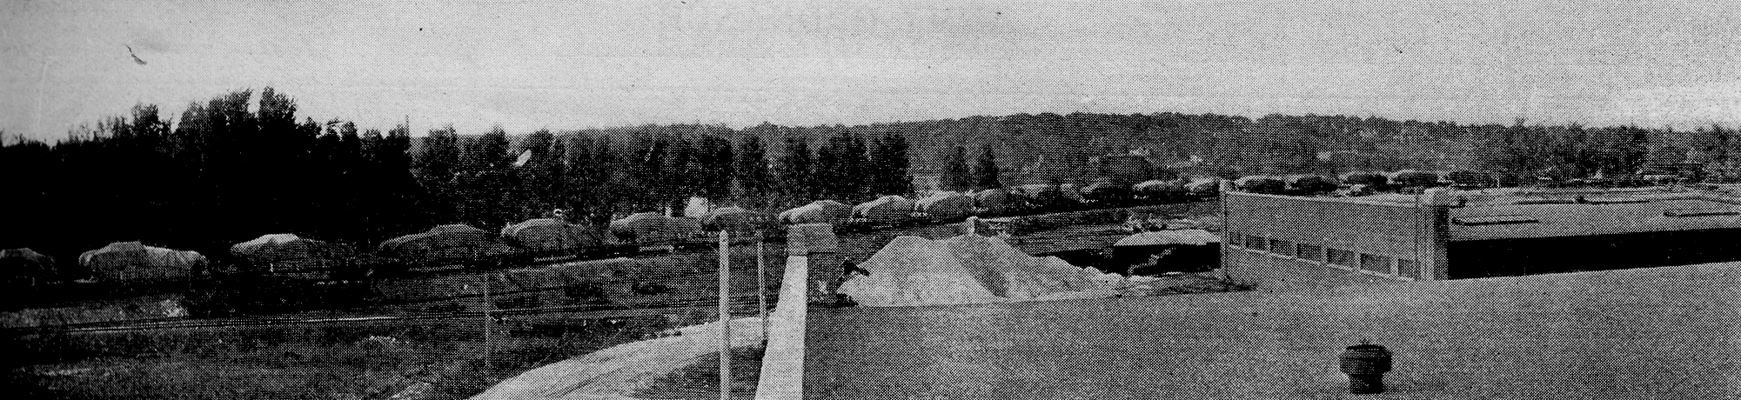
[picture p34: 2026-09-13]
references/1920-07_Manufacture_of_Mark_VIII_Tanks/Article_Project/assets/transport_right.png

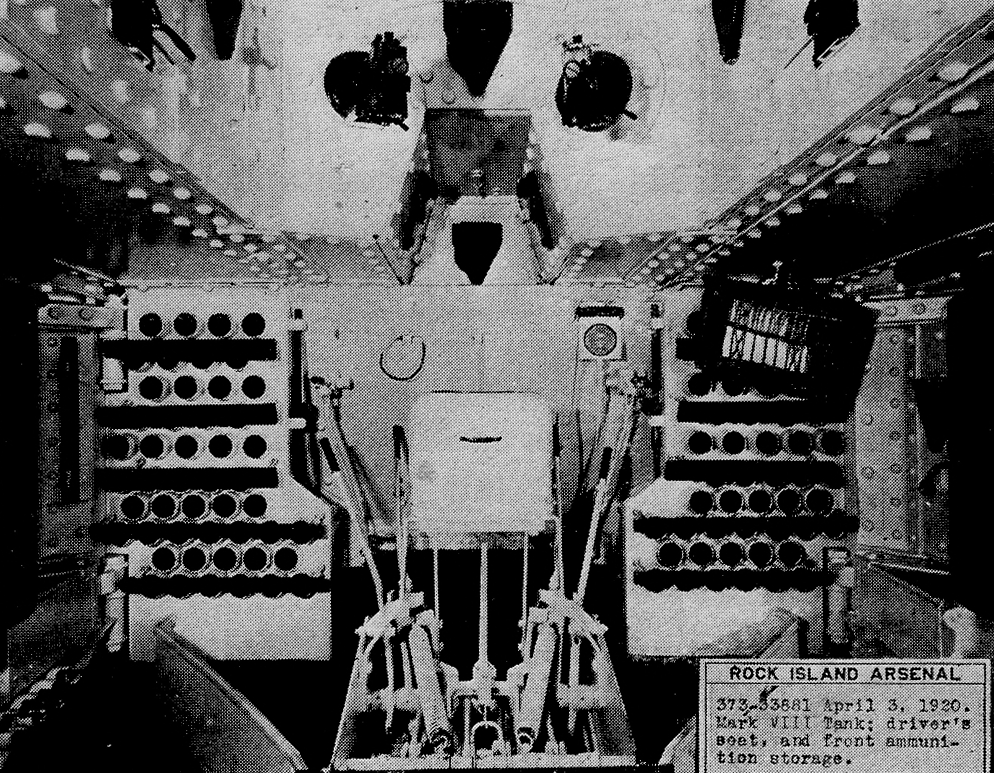
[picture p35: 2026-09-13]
references/1920-07_Manufacture_of_Mark_VIII_Tanks/Article_Project/assets/driver_interior.png

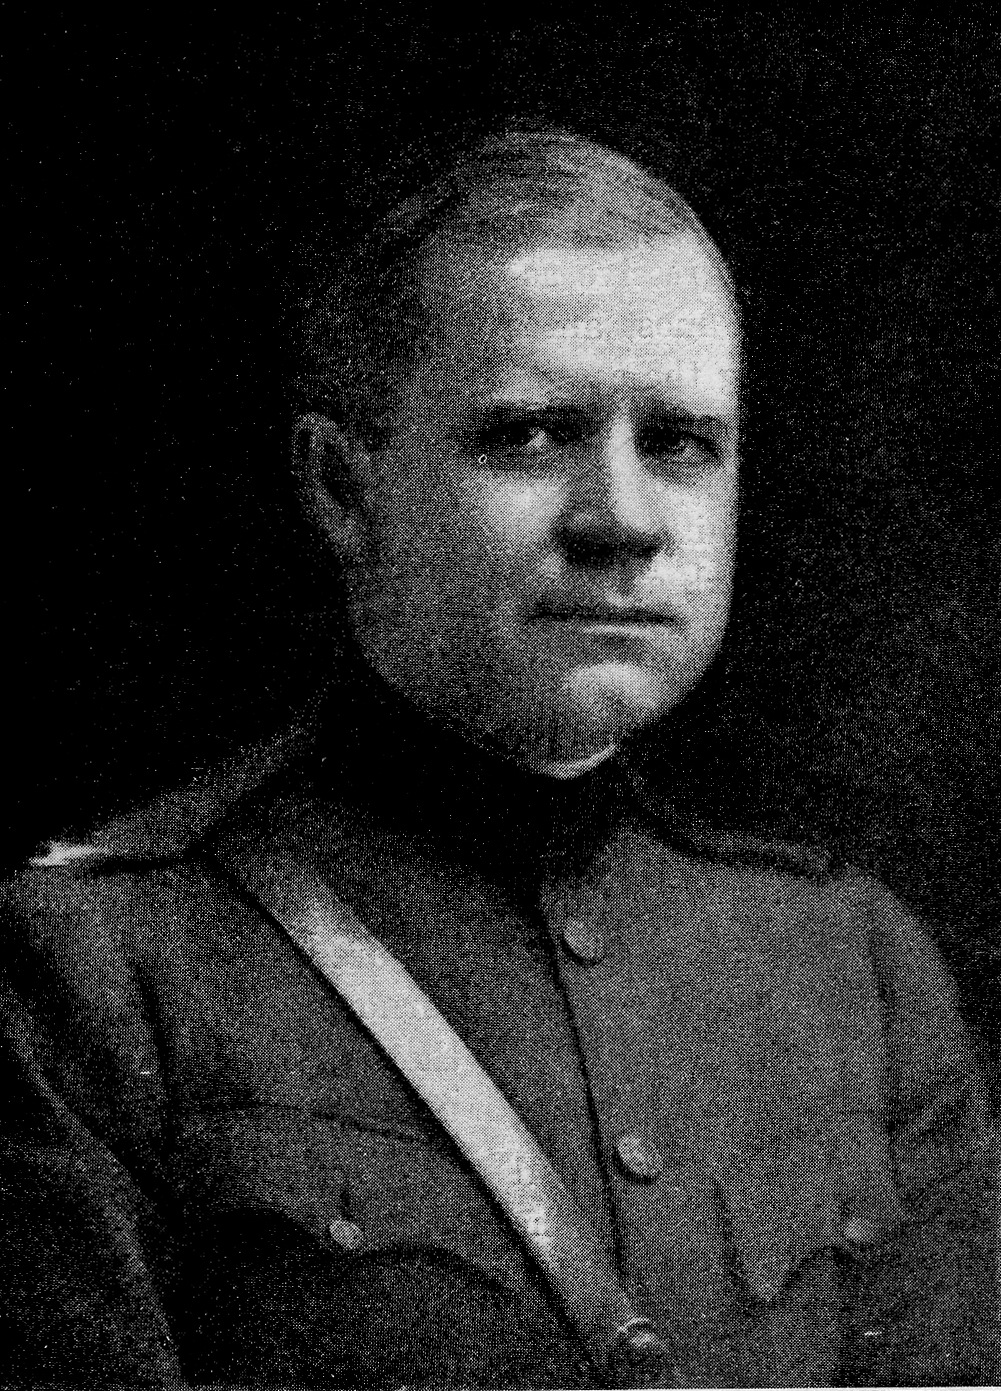
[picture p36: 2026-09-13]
references/1920-07_Manufacture_of_Mark_VIII_Tanks/Article_Project/assets/jordan_portrait.png

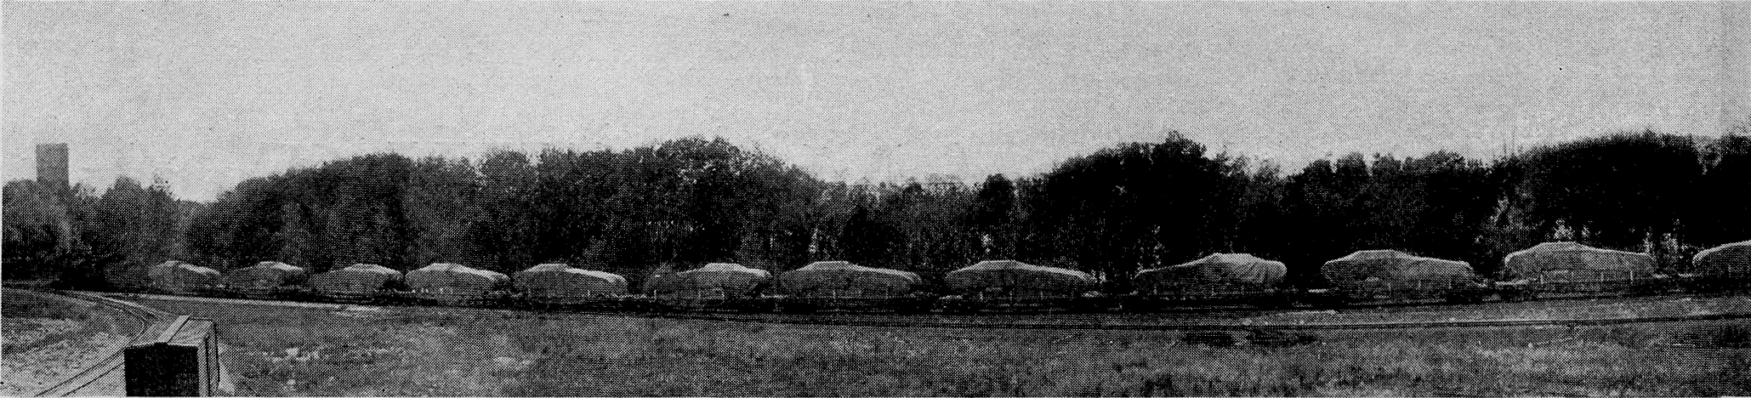
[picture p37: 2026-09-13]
references/1920-07_Manufacture_of_Mark_VIII_Tanks/Article_Project/assets/transport_left.png

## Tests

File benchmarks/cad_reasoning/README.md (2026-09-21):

# CAD reasoning CLI pilot

This benchmark compares GPT-6 Astra at medium, high and xhigh effort on three
bounded tasks drawn from the Mark VIII reconstruction. It is a pilot for choosing
where to spend reasoning effort, not qualification of a cheaper production model.

## Protocol (fixed before candidate runs)

- Three cases, three efforts, three repetitions: 27 independent CLI sessions.
- Source case: interpret full SNL Plate 21 with two catalogue transcriptions;
  distinguish callouts 28/30, their spatial locations, and unsupported dimensions.
- Construction case: emit a FreeCAD function for a fully specified nested bearing
  and 24-groove sleeve, including a supplied nontrivial installation transform.
- Repair case: diagnose and repair the historical collar Boolean defect while
  preserving the qualified rear mounting lip and its six holes.
- Each session receives its entire task inline, plus the source image where
  applicable. No conversation history, model answers, grading code or later
  project corrections are supplied. Tools are prohibited in the task and tool
  events are audited; any use invalidates that trial. This is prompt-enforced
  and audited isolation, not a claim that the CLI filesystem sandbox prevents
  reading every other file on this system.
- The child task is read-only and runs in a fresh empty directory. Candidate code
  is returned as structured text and executed by a separate FreeCAD grader.
  Thus this pilot measures bounded interpretation/code generation, not autonomous
  research, tool selection, long-context integration or CAD debugging loops.
- Candidate functions receive three construction scenarios or five repair sizes.
  Hidden checks evaluate material witnesses, voids, alignment, nesting, preserved
  material and independent STEP round trips. A reference implementation and
  deliberately faulty implementations check the grader before experiments.
- All hard checks must pass for a case pass. Record continuous scores as diagnostic
  detail; a high average never overrides a failed hard requirement.
- Source endpoint windows are approximate manual traces, not dimensional
  calibration. Explicit uncertainty is retained as a useful outcome but cannot
  earn a pass on a required supported identity/arrangement decision.
- Rotate effort order across repetitions. Keep model, prompts, images, runtime,
  schema and grader fixed. Repetitions are not additional distinct problems.
- Record command, requested settings, CLI version, hashes, elapsed time, exit
  status, raw events, final answer, token/cache usage, tool events and grading.
  Requested model/effort are recorded; do not claim server-side attestation when
  the event stream does not return it.
- Separate infrastructure failures from modeling failures. No automatic repair,
  retries that hide failures, model-based grading or access to reference answers.
- Existing project CAD and source files are read only. No production promotion.

## Interpretation

The main outcome is per-case hard-check success. Token usage and wall time are
secondary; cached input must be reported separately. No dollar estimates are
inferred from ChatGPT-authenticated CLI token counts. Three repetitions per case
are too few for a general reliability claim. A passing result supports another
bounded trial, not lowering effort for untested mechanisms or integration.

## Run

`python3 benchmarks/cad_reasoning/prepare.py`

`python3 benchmarks/cad_reasoning/grade.py --self-test`

`python3 benchmarks/cad_reasoning/run.py`

`python3 benchmarks/cad_reasoning/summarize.py`

CLI launches need their normal authentication, network and runtime-state access.
The child sessions themselves use a read-only sandbox. Results and grading logs
live under `results/`; durable temporary directories are under `.work/`.

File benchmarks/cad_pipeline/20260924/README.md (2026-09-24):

# Brake-stop replay and selective reuse — 24 September 2026

The deterministic runner completed all 18 real development stages: native build,
extraction, independent part/interface/joint/context checks, preservation, STEP
exchange, rendering/comparison, independent rebuild, and parameter variation.
The replay matches the previously qualified trial04 exactly for 1,537 archived
BReps, 139,961 persistent properties and every object type. Archive container
hashes can differ while all these contents match.

| Invocation | Executed | Reused | Recorded stage execution time |
|---|---:|---:|---:|
| Initial replay | 18 | 0 | 872.17 s |
| Corrected comparison dependency | 1 | 17 | 0.21 s |
| Unchanged replay | 0 | 18 | 0 s |

The first manifest omitted the suspension report read by the source-comparison
stage. It was added after that invocation completed. The next invocation reran
only that stage; the third reused all 18. Read-only verification then found every
stage current. This documents a manifest correction, not a claim of automatic
complete dependency discovery.

These times exclude runtime probing, hashing and orchestration; they are not
end-to-end speedup measurements. Assistant token usage and reviewer time were not
measured. The runner invoked no model. Its 11 failure/reuse/locking tests passed.
No broad change of model or reasoning effort follows from this result.

[summary.json](summary.json) binds the plan, checker results and original/replay
native hashes. Invocation records retain per-stage evidence paths. Full run logs,
outputs and immutable attempts remain in `.work/cad-pipeline/brake_stop_pipeline01`.
The [pipeline README](../../../tools/cad_pipeline/README.md) gives recovery and
freshness commands. The original trial04 remains the retained reviewed artifact;
this replay does not promote its historical interpretation or modify standard tank011.

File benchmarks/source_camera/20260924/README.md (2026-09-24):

# Source-camera controls — 24 September 2026

This is a **synthetic known-camera experiment using real saved transmission
geometry**, not a fit to a historical photograph. It tests the complete path from
FCStd archive/placements through image fitting, calibrated raster rendering and
camera reuse. Bounding-box datums are synthetic controls, including points in
empty space; historical picks must identify actual image features instead.

The control uses 12 fitting points and four held-out points from four saved
transmission-frame/bearing occurrences. The perspective camera is generated
independently from a known position, rotation and focal length. The recovered
camera's maximum held-out reprojection error is below 1e-9 pixels. This exact,
noise-free control tests implementation; it says nothing about attainable accuracy
on historical scans or uncertain geometry.

The first durable numerical fit took about 0.0023 s; reuse/reassessment took about
0.00043 s, excluding native verification, image I/O and rendering. Both use the
same camera hash and produce byte-identical geometry and overlay images. Small
numerical fits are inexpensive here; retaining source research and reviewed
landmark identities is the more important efficiency improvement.

- [Known camera](native_control/known_camera.json)
- [Landmark packet](native_control/packet.json)
- [First assessment](fit01/assessment.json), [overlay](fit01/overlay.png)
- [Reused assessment](reuse02/assessment.json)

Eight numerical/cache/raster tests cover known perspective, orthographic and
oblique projections; fixed-camera holdout conflicts; reviewed refits with old
fits preserved; wrong/altered images; tampered fit records; planar/insufficient
anchors; wrong projection; missing holdouts; robust-fit outliers; and reciprocal
depth occlusion. Three actual-native negative tests reject altered frames, changed
archive shape bindings and stale anchor definitions. These do not automatically
accept any historical camera.

The initial CLI render attempt used a relative packet argument with the headless
launcher, which changes working directory; it failed before fitting. Absolute
arguments resolved it. The tested commands and current limitations are in the
[source-camera README](../../../tools/source_camera/README.md).

Handbook plate79 has been visually classified as a promising perspective
photograph, but no historical fit is claimed. Its trusted spatial landmarks and
independent holdouts are a separate open evidence decision in the tank ledger.
The existing fixed-register HB134/135 comparisons remain unchanged.

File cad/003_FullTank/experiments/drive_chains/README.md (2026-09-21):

# Drive-chain research and isolated native studies

These studies prepare the next drivetrain increment. They do not populate the
delivered assembly or reconcile the catalogue's chain component quantities.

- `source_rows.json` and `source_review.json` retain source records and inspected
  image hashes. HB130 directly documents 12 driving-sprocket teeth.
- `pitch_route_probe.py` tests discrete 50-pitch closure and a literal 25-axis
  interpretation. `installed_pitch_route_probe.py` aligns the 50-pitch route
  with the existing roller-pinion relief phase.
- [Source overlay](route_comparison.html) compares that mathematical candidate
  with unchanged SNL Plate2 pixels. It was browser-rendered and inspected.
- `roller_clearance_probe.py` tests the source-sized roller envelopes against
  the casting. `roller_clearance_build/report.json` and the saved/reopened
  native fixtures retain both failed cases: 16 overlaps at the current relief,
  three at the enlarged candidate. These failed circular-pocket cases remain
  preserved even after the later tangent-flank candidate passes.
- `flank_clearance_probe.py` and `sprocket_geometry.py` test repeated root seats
  and tangent straight flanks. The selected 20-degree candidate preserves a
  0.25 mm static roller gap. Its profile is a reconstruction assumption.
- `build_chain_candidate.py`, `chain_parts.py` and the explicit controls create
  a saved/reopened 252-leaf native fixture: 250 chain components and two sprockets.
  All 443 candidate material pairs pass; bar/pin/cotter details remain partial.
- `installed_chain_probe.py` places both handed chains against the current tank.
  Its 504 new leaves replace two existing castings for comparison. The 886 internal
  and 260 external candidate pairs have 18 overlaps, all with the provisional
  M2003 engine-room back plate. This failed installation is retained.
- `casing_passage_probe.py` independently tests an M2003 opening hypothesis.
  HB134's casing width and SNL60/170's M1592-to-M2003 connection motivate the
  passages. The reopened 505-leaf fixture passes 904 internal and 255 external
  candidate pairs with zero overlap; the existing 77-plate hull checks also
  pass. The detailed opening shape and clearances remain inferred. Later
  studies below check the actual casing bodies and wall attachments.
- `casing_source_rows.json` identifies the body/cap assemblies and their named
  components. `casing_joint_review.json` preserves newly inspected cap-bolt
  allocations and conflicts between nested rivet counts and joint tables.
- `casing_parts.py` and `casing_shell_probe.py` build separate M1590 bodies and
  M1591 caps. The initial `casing_shell_build` retains two 21.609290 mm³ wall-corner
  overlaps and its exact input snapshot. Its original half-section raster has
  a documented rendering error and must not be used as geometry evidence.
- `casing_shell_passage_build` uses the actual casing section to enlarge the
  inferred wall openings. Its 509-leaf fixture passes 638 casing-related material
  pairs, with 2.304985 mm minimum wall clearance and 2 mm hub clearance. The
  corrected [half section](casing_shell_passage_build/casing_half_section.png)
  was inspected. The cap seam and detailed shell contour remain inferred.
- `casing_wall_mount_probe.py` adds two M1592 angles, 22 wall rivets and 34 casing
  rivets to the fixture. Its 567 reopened leaves pass 697 new/changed material
  candidate pairs, 56 receiving bores and 56 two-receiver seating checks.
  The [attachment detail](casing_wall_mount_build/wall_joint_detail.png) was
  inspected. Angle form, section and hole pattern remain explicit assumptions.
- `casing_cap_parts.py` and `casing_cap_probe.py` add 94 leaves: eight M1583 side
  cleats, four M1593 roof cleats, four M1584 packing strips, 36 cleat rivets and
  fourteen separate bolt/nut/lock-washer sets. Original SNL128/270 inspection
  supports the separate nut and washer identities; SNL31 supplies the set count.
  `casing_cap_build` preserves a rejected centered roof-rivet pattern with four
  bolt/nut intersections. Its exact inputs and inspected images are retained.
- `casing_cap_clearance_build` offsets the middle roof rivet by an inferred
  24 mm. Its 661 saved/reopened leaves pass 914 new/changed material pairs,
  50 receiving bores, 50 seating checks and 14 fastener-envelope retention
  checks. The [joint detail](casing_cap_clearance_build/cap_joint_detail.png)
  was inspected. Detailed threads, spring action and clamp loads are unqualified.
- `casing_cap_packing_build` supersedes that candidate's packing location.
  Original HB185 explicitly puts M1584 under the cleats. The revised strips sit
  between each body side-cleat foot and the sheet; mating flanges meet directly.
  Its 661 leaves pass 914 material pairs, 50 bores, 50 seats, 14 retention checks
  and four packing-contact checks. Earlier passing geometry is retained as a
  rejected source interpretation, not promoted as the current reconstruction.
- `casing_trim_parts.py` and `casing_trim_probe.py` add eight register plates,
  eight beading strips, 32 button rivets and 40 countersunk rivets. The 749-leaf
  `casing_trim_build` passes 1,088 material pairs, 72 bores, 72 seats, eight lap
  contacts and 40 flush-head checks. Its [native rivet section](casing_trim_build/beading_rivet_section.png)
  and inner/outer views were inspected. Profiles and exact edge assignments are
  inferred. `casing_trim_sources.json` retains the HB M1586 alternative and the
  SNL global/nested beading-rivet quantity conflict.
- `casing_support_probe.py` adds four M1587/M1588 brackets, 28 case rivets and
  eight assumed three-part hull fastening sets. Four drilled hull receivers
  join the isolated fixture. Its 809 reopened leaves pass 920 material pairs,
  36 bores, 36 fastener seats, four bracket contact checks and eight retention
  checks; existing 77-plate hull validation also passes. The
  [support installation crop](casing_support_build/casing_support_detail.png)
  was inspected. Bracket forms and hull bolt size/count/placement are assumptions.
- `audit_casing_inventory.py` independently reads saved native link ownership.
  The fixture contains 300 selected casing occurrences, including 42 named
  components across all twelve selected SNL casing marks. The audit reports
  actual hardware counts and retains every known quantity/identity conflict;
  it does not declare historical inventory reconciliation or standard promotion.
- `chain_detail_probe.py` forms 100 split-pin tails and drills 400 inferred oil
  passages through the 200 link-bar occurrences. The saved/reopened 809-leaf
  fixture passes 274 new material pairs, 100 cotter capture checks, 100 pin
  retention checks, 400 oil-to-journal paths and 200 orientation checks. Unformed
  cotters and undrilled bars supply negative controls. HB24/132/134 establish the
  functional features and split-pin size; passage dimensions and tail form remain
  assumptions. The [joint detail](chain_detail_build/chain_joint_detail.png) and
  [bar-aligned oil section](chain_detail_build/oil_sections/inner_bar_oil_section.png)
  were inspected. `inspect_chain_oil_sections.py` supplies separate local sections
  because the joint overview cuts obliquely across the individual oil passages.
- `transmission_output_probe.py` adds two M289 output shafts and two M292 brake
  drums. HB122 and SNL215 distinguish M289 from the central M255 cross shaft.
  A conditional scale from HB132's four-inch sprocket hub controls the adjoining
  proportions. The [native/source overlay](transmission_output_build/source_section_overlay.png)
  was inspected. Four spline fits and two hub seats pass, but the 813-leaf
  candidate retains two 23,938.321999 mm³ drum/casing clashes.
- `casing_front_probe.py` tests a symmetric small-end taper from the retained
  168.275 mm maximum width to an inferred 132 mm. The 813-leaf candidate passes
  764 material pairs, eight three-mm normal sheet-thickness witnesses and both
  chain/drum clearance checks. Its [native section](casing_front_build/casing_output_plan_section.png)
  was inspected. The rear attachment region is geometrically unchanged. The
  taper and stations are assumptions; the earlier failed candidate is preserved.

- `transmission_bush_probe.py` adds two M296 inner sleeves, two M299 outer sleeves,
  four separate M300 bronze dowels and four M290 retaining rings to the saved
  casing/output fixture. The two shared M289 shafts gain inferred grooves and
  blind dowel pockets. All 825 reopened leaves are valid single solids; 26
  changed/new material pairs have no overlap. Four journal-clearance, four
  dowel-capture and four bidirectional ring-capture checks pass, including
  undrilled/ungrooved controls. The
  [axial section](transmission_bush_build/output_bush_section.png) and
  [source overlay](transmission_bush_build/source_bush_overlay.png) were inspected.
- `qualify_output_bush_interfaces.py` independently reopens that fixture and
  checks all four sprocket/drum spline interfaces. The engagement regions have
  zero material difference from the original shafts; clearances and twist
  capture remain valid. This is separate from complete axial-stack retention.
- `transmission_support_research.json` records inspected fixed-bracket/cap source
  lists. SNL309 requires poured babbitt; HB209 separately names brasses and shims.
  Their relationship remains open. The M391 foot schedule conflicts (four nested,
  two standalone); cap wool waste is a mass quantity, not a count of two parts.
  These questions remain explicit for the next fixed-support increment.
- `transmission_support_probe.py` now constructs two each M293/M297 brackets,
  M294/M298 caps, four common M295 oil-box lids and eight separate poured-lining
  half regions. The latest `transmission_support_clearance_build` has 845 valid
  reopened solids and retains all 825 prior occurrence signatures. Four local
  bearing fits pass, and all twenty additions survive STEP export/reimport.
  **The installation is rejected for integration:** each outer bracket meets
  the casing wall and one wall-angle rivet. Seventy material candidate pairs
  yield four overlaps. See the [interference view](transmission_support_clearance_build/support_interference.png)
  and [source overlay](transmission_support_clearance_build/source_support_overlay.png).
  Two earlier native trials preserve a lid/cap overlap and a touching lid-seat
  edge; the latest adds a flat seat with perimeter clearance. Six latest rasters
  were inspected. The bracket vertical profiles remain provisional.
- `transmission_frame_research.json` records inspected SNL96/97 frame members and
  HB/SNL orientation evidence. The next study must reconstruct the top/bottom
  channels, angles and gussets, then resolve the bracket/casing relationship.
  Source drawings support aft-facing feet and upward-opening cups; no unsupported
  casing opening or bracket rotation is used to force the candidate to pass.

Native probes accept `--stage` pointing to the current standard model or its
byte-identical authored pinion origin and
an optional `--output`. They do not modify that stage. The complete chain
candidate includes bars, bushes, pins and initially unsplayed cotters; the detail
candidate adds formed tails and oil passages. The older circular
clearance probe contains only diagnostic annuli. Casing shells and their wall
attachments, cap cleats, beading, register plates and supports are now separate
candidates. Partial output shafts and brake drums now have a tested static
interface. Shaft sleeves, dowels and groove-seated rings pass their local checks.
Fixed bearing housings/lining are now modeled in a candidate needing interface
revision. Source reconciliation, frame attachment and complete axial retention,
brake bands, lubrication performance and full-model integration/parameter
qualification remain. Full
inventory, moving engagement and historical-fit claims remain false.

The subsequent `transmission_frame_probe.py` study adds fifteen separate frame
members and revises the four bracket webs. The first `transmission_frame_build`
has nineteen interferences and is retained as rejected evidence. The revised
[frame candidate](transmission_frame_clearance_build/TransmissionFrameCandidate.FCStd)
has 860 valid leaves, 126 material pairs without overlap and 34 passing contact/gap
checks; 841 earlier occurrences are unchanged. Five rasters were inspected.
The source comparisons distinguish projected mounting pads from the actual
shaft-height section. Outside angles are now at the frame ends, overriding the
earlier generic controls wording about bearing stations.

This is only a nominal fit: the outer casing gap is 0.236 mm and nearby assumed
stem shapes collide. `check_transmission_frame_sensitivity.py` preserves those
negative witnesses and rechecks four bearing interfaces; its expected outcomes
pass, but parameter-envelope and historical qualification remain false. The
5.806-mm inner pad/channel gap still needs an evidenced attachment. Main/additional
fiber packers are recorded in `transmission_mounting_research.json`; their source
quantity conflict and unknown receiver prevent treating them as this gap's filler.
Frame rivets/bolts, hull mounting, brake attachments and central bevel case remain
pending. Main standard 011 is unchanged.

`transmission_lid_probe.py` continues from that saved frame. The latest
`transmission_lid_clearance_build` has 864 valid leaves, adding four source-size
steel pins and integral hinge features on four caps and four covers. The other
852 occurrences are unchanged. Thirty new/changed material pairs, four static
hinge/retained-bearing checks and twelve-solid STEP reopening pass. The rejected
`transmission_lid_build` preserves four cup-rim interferences with the lower
hinge-axis assumption. Covers remain closed; pin retention and motion are not
qualified. See the [cap detail and handbook comparison](transmission_lid_clearance_build/hinge_review/source_hinge_detail.png).

Pin dimensions use exact cylindrical surfaces and volume, not tessellation-cached
bounding widths. The new material filter removes display triangulation first.
`check_transmission_frame_bounds.py` independently rechecks all nineteen earlier
frame/bracket changes with cleaned bounds: the same 126 pairs, no new overlap.
`transmission_stud_research.json` records the physical stud identities, nuts and
split pins from original SNL241/124. Bare stud identities differ from nested stud
assembly identities. The existing estimated ear depths cannot override the
printed 3⅝-, 4⅞- and 5½-inch stud lengths. Cap fastening and lubrication are next.

`transmission_stud_probe.py` now installs those sixteen studs, sixteen castle
nuts and sixteen formed split pins in fixed-bearing subassemblies. The latest
`transmission_stud_clearance_build` has 912 valid leaves, with eight changed
receiving castings and 856 unchanged earlier occurrences. All sixteen fastening
checks, four retained bearing/hinge checks and the 56-solid STEP reopening pass;
262 material candidate pairs have no overlap. The preserved first trial has two
small port cotter-eye/casing overlaps. Rotating the port pins about the stud axes
points their eyes outboard and clears those overlaps.

The printed stud lengths constrain inferred blind bosses and spotfaced nut
seats. Threads remain cylindrical envelopes, and nut dimensions and split-pin
form are estimates. `check_transmission_stud_allocation.py` swaps MX10/MX36
between the inner upper/lower corners: its 41 candidate pairs also clear.
Neither feasible arrangement establishes the historical allocation. See the
[source comparison](transmission_stud_clearance_build/source_review/source_fastener_detail.png)
and candidate `visual_review.json` for the remaining visible discrepancies.

`transmission_oil_fitting_research.json` records the next SH664A elbow, SH664B nut
and SH664C sleeve inventory. Original SNL67 also lists a distinct A16323 brass
collet; its relationship to the sleeve is unresolved. Complete lubrication,
frame attachment, the central transmission and integration remain open.

`transmission_oil_probe.py` now populates one SH664A elbow, SH664B nut and SH664C
sleeve per cap, plus four separate porous wool volumes and low galleries through
the caps/front linings. `transmission_oil_build` reopens with 928 valid solids:
twelve new fittings, four material envelopes, eight changed cap/lining
occurrences and 904 unchanged prior occurrences. Its 104 material pairs have no
overlap. Four fitting/passage checks, four retained interface checks and the
24-solid STEP reopening pass. All sixteen existing nut seats and their protected
cap material remain unchanged.

The local [fitting section](transmission_oil_build/oil_fitting_section.png) and
[bearing section](transmission_oil_build/bearing_oil_section.png) expose the
inferred connection. The [handbook comparison](transmission_oil_build/source_review/source_oil_detail.png)
records the remaining rounded-casting and upper-opening differences. Original
SNL261/262 supplies the explicit ¼-inch tube outside diameter; original SNL274
confirms eight ounces of wool total, represented as four two-ounce material
envelopes rather than eight discrete parts. The packing conforms to cap hinge
intrusions. Thread form, sealing, full feed lines and oil performance remain
unqualified. All source rows, assumptions and exact build inputs accompany the
native candidate; no new standard milestone has been promoted.

`check_transmission_oil_gallery.py` adds twelve local trials. Nominal, height and
bore variations retain the specified 1-mm wall and open route; the two lowered
negative cases miss the reservoir. All expected outcomes pass. The test bounds
are diagnostic assumptions, with historical route and whole-assembly parameter
qualification still open.

`transmission_core_probe.py` adds eleven major central parts to that fixture:
the M263/M264 bevel case and cover, M255 cross shaft, and two each M278/M277
case halves, M286 carriers and M269 high-speed drums. The
[saved native candidate](transmission_core_build/TransmissionCoreCandidate.FCStd)
has 939 valid single-solid leaves, with all 928 earlier occurrences unchanged.
Thirty-three material pairs have no overlap; nine specified interface checks
pass, with five additional diagnostic distances recorded. Eleven new solids
pass STEP roundtrip. Twelve local source-trace/phase/end-position trials have
their expected outcomes, including deliberate collision cases.

The [oblique view](transmission_core_build/transmission_core_oblique.png),
[cutaway](transmission_core_build/core_horizontal_cutaway.png),
[Plate22 overlay](transmission_core_build/source_plate22_overlay.png) and
[Plate23 comparison](transmission_core_build/source_review/source_plate23_overlay.png)
were actually inspected. The latter records a visible mounting-plane mismatch;
input centering differs by about32mm between the local Plate22 projection and
the assumed tank centerline. Printed M269 diameter381mm is retained despite a
larger scaled scan extent. Gears, bearings, brake bands, joint hardware and full
lubrication remain open. This remains an isolated partial reconstruction; see
the [central transmission packet](../../packets/I03-transmission-core.md).

`transmission_planet_probe.py` extends that fixture with the paired large
planetary trains and retention: eighteen new occurrences, five revised case/shaft
occurrences and 934 unchanged components. The
[saved native candidate](transmission_planet_build/TransmissionPlanetCandidate.FCStd)
contains 957 valid solids. All 110 material candidate pairs are clear; 24
specified interface checks, ten native gear-tooth counts and six planet mesh
checks pass. All 23 new/changed solids survive STEP roundtrip.

The [gear detail](transmission_planet_build/large_gears_oblique.png),
[cutaway](transmission_planet_build/transmission_gear_cutaway.png) and
[source comparison](transmission_planet_build/source_review/source_detail.png)
were inspected. HB126 supplies 18/27/72 teeth at 4–5 DP; pressure angle, root
form, backlash, axial details and enlarged case seats remain approximations.
The comparison records a 5.129 mm axial station discrepancy and a substantial
sun-outline difference. `check_transmission_planets.py` confirms 28 expected
local outcomes, including deliberately incorrect tooth phases and axial stops.
These do not qualify historical fits, full motion or the uncertainty envelope.
See the [large-gear packet](../../packets/I03-large-planetary-gears.md) for source
identities, remaining pin/bush work and reproduction commands.

`transmission_pin_probe.py` adds 56 pin, bush, sleeve, ring and fastening
occurrences from ten source identities. The
[saved candidate](transmission_pin_build/TransmissionPinCandidate.FCStd) has
1,013 valid solids; two carriers change and 955 prior occurrences are unchanged.
The carrier nuts sit in source-scaled recessed seats. All 332 material candidate
pairs are clear and 108 specified interface checks pass. All 58 exported solids
have empty native/STEP material differences; mass-property deltas remain recorded.

`check_transmission_pins.py` confirms 50 expected retention failures, six axis
alignments, four hardware sizes and 11 deliberate export-displacement failures.
The [pin-axis section](transmission_pin_build/source_review/pin_axis_section.png)
and [source comparison](transmission_pin_build/source_review/source_pin_comparison.png)
expose the bearing stack and the unresolved source radial discrepancies. The
ring-bolt position requires a carrier-rim/pin-ring review before integration.
See the [support packet](../../packets/I03-large-planet-supports.md) for source
corrections, bush identity conflict, approximations and reproduction commands.

The subsequent [ring-support revision](transmission_ring_support_build/TransmissionRingSupportCandidate.FCStd)
corrects the M318 source feature and station. Callout15 identifies the inner
bolt; the prior comparison used an unrelated outer case-joint bolt. Twenty-two
occurrences change, with 991 retained unchanged in the 1,013-solid fixture.
All 166 material pairs, 108 interfaces and 22 STEP material comparisons pass.
Fifty local access/stop trials, six radius/diameter checks and five deliberate
STEP displacement checks pass. The
[source comparison](transmission_ring_support_build/source_review/source_pin_comparison.png)
and [bolt section](transmission_ring_support_build/source_review/bolt_axis_section.png)
show the corrected station and inferred recessed receivers. See the
[revision packet](../../packets/I03-ring-bolt-station.md); exact cast contours,
case fastening, small gears and central bevel/input work remain open.

The preceding [small planetary candidate](transmission_small_build/TransmissionSmallCandidate.FCStd)
adds 46 occurrences: both small gear sets, separate sun bushes, input disks,
rings and 32 rivets. One cross shaft receives smooth sun-bush journals, while
1,012 earlier occurrences remain unchanged. All 166 material candidate pairs,
182 interfaces, ten native tooth counts, six gear meshes and 47 STEP material
comparisons pass. Thirty local trials, eight native dimension checks and seven
intentional STEP-displacement checks also pass. The [small-train packet](../../packets/I03-small-planetary-gears.md)
records the inferred 24-tooth planets, printed M276 row conflict and open source
profile discrepancies. The [source comparison](transmission_small_build/source_review/small_train_comparison.png)
and [combined cutaway](transmission_small_build/source_review/coupled_trains_cutaway.png)
show how the new gears fit the retained assembly; small supports, brake bearings,
retention and standard integration remain unfinished.
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

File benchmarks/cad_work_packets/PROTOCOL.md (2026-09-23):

# Tool-enabled CAD work-packet trial 01

Frozen before inference, 22 September 2026. This is a second, distinct experiment;
the earlier no-tools pilot remains unchanged.

Compare requested GPT-6 Astra medium and xhigh once each on three work packets,
using fresh CLI sessions with local tools and the same inputs per pair. Run
stack medium/xhigh, mount xhigh/medium, spring medium/xhigh, sequentially.
Each candidate gets 480 seconds, followed by up to 180 seconds of independent
validation. A failure remains in the results. Diagnosis, if needed, is a separate
xhigh run whose time/tokens are additional correction cost, not a replacement score.

- Stack: synthetic, internally reviewed pin/tube/bush specification, two parameter
  sets, nested transformed assemblies, shared definitions and four installed links.
  Several major dimensions derive from HB141; bush fits and pin hollow are fixture
  assumptions. Passing cannot qualify this simplified stack as historical tank CAD.
- Mount: synthetic native assembly with two damaged occurrence placements, two
  differently oriented parents, shared shapes and ten physical occurrences. The
  candidate must diagnose it through FreeCAD, preserve the qualified fixture shapes
  and all undamaged placements, and export the repaired installed geometry.
- Spring: original HB141 spread and full extracted section plate 138, a conditional
  wire interpretation and a deliberately false draft memo. Preserve printed wording,
  derive literal and alternative clearances, identify parts and retain the unresolved
  evidence gate. No final spring geometry is requested.

Acceptance is implemented outside candidate write/read access. Validators consume
saved CAD or JSON, never import candidate builders. Before trials, three reference
answers must pass, and four intentional defects must fail. Each run probes its
filesystem policy, records requested settings, input/controller/validator hashes,
raw events, usage, timing, artifacts, checks and production CAD hashes. Shell
network access is disabled. Source/visual review is an additional recorded gate.

Report mechanical pass rates, tool use, source/visual findings, total input and
output tokens, and CLI time separately. Count diagnosis overhead when present.
There is no automatic integration or claim that one trial establishes reliability.
This is still an effort comparison within Astra, not a comparison with cheaper
model families. CLI events do not attest the model actually served. Do not infer
billing from these token fields.

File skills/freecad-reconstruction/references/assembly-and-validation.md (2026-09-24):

# Assembly geometry and validation

These operational details were exercised with FreeCAD 1.1.1 / OCC 7.8.0 on
22 September 2026. Recheck API assumptions after a runtime upgrade.

## Definition and occurrence coordinates

Prefer a reusable definition at its documented local origin, with identity
placement, and place its `App::Link` occurrences relative to their owning
`App::Part`. For an ordinary nested rigid hierarchy:

```python
world = outer.Placement.multiply(inner.Placement).multiply(link.Placement)
```

The rightmost transform acts first. Do not assign this world placement back to
the child: the assembly would apply its ancestors again. Use three non-collinear
points or a full rigid matrix to verify orientation as well as translation.

The tested `App::Link` object does **not** expose `getGlobalPlacement()`, although
`App::Part` does. For a direct, unscaled link to an identity-frame shape definition,
the parent's global placement multiplied by the link's placement is its world
placement. The supplied helper walks ordinary geometric parents and explicitly
checks this narrower contract. Do not silently apply it to linked assemblies,
scaled links, or nonidentity definition frames. In the MarkVIII repository,
`cad/003_FullTank/lib/cad_build.py:leaves` handles the established delivery's
nested external links; inspect its conventions before extending that model.

`App::Part` creates Origin/axis/plane objects automatically. Count physical
definitions and installed links by role/type, not `len(doc.Objects)`. A library
definition and its installed occurrences must not both enter the physical BOM.

## BRep and surface construction

Keep cylinders, planes, cones and revolved analytic profiles analytic where that
matches the evidence. Booleans can return a compound containing one solid; check
`isValid()` and `len(shape.Solids)`. Inspect the actual topology before assuming
attributes specific to a solid, such as its `CenterOfMass`, are present on a
generic imported `Part.Shape`. Use the constituent solids for aggregate centroids.

On FreeCAD 1.1.1 / OCC 7.8.0, `removeSplitter()` can return invalid topology
without raising an exception. A grooved bearing passed validity after every
Boolean cut, then failed only after same-domain face unification. The operation
also mutated its input BRep. Running `shape.copy().removeSplitter()` preserved
the original and produced a valid result in the focused probe. Isolate optional
cleanup on a copy, and check the returned shape before replacing the original.
If cleanup fails, retain the checked original BRep and record that choice;
saved-native and exchange checks still apply. The project retains the
[focused probe and before/after BReps](../../../cad/003_FullTank/experiments/drive_chains/engine_crankshaft_build/diagnostics/groove_probe/).

Validity alone also does not prove that optional cleanup improved a shape. In
the lower-drive receiving case, the same `removeSplitter()` operation returned
a valid single solid but raised its maximum kernel tolerance from about
5.10e-6 to 1.015e-4 mm at intersecting cone/cylinder boundaries. The original
and cleaned shapes had zero material differences in both directions. Keeping
the valid shape before cleanup passed the original strict STEP criteria, with
about 1.28e-7 mm maximum STEP tolerance. Compare the tolerances as well as
validity before adopting an optional cleanup; retain the original when cleanup
degrades the representation. Do not reset tolerances to hide the change. The
[saved diagnostic and replay](../../../cad/003_FullTank/experiments/drive_chains/engine_lower_drive_installation/diagnostics/cleanup_tolerance/README.md)
records this FreeCAD 1.1.1 / OCC 7.8.0 case.

For a prismatic rounded opening, prefer one planar wire of tangent lines and
analytic circular arcs, extruded once. In the lower distribution housing study,
an equivalent tool assembled from boxes and cylinders left higher-tolerance
intersection edges after Boolean operations. Both housing halves reopened from
STEP with slightly increased kernel tolerances despite zero material differences.
The single-profile prism preserved material in both directions and passed the
original tolerance bounds. Diagnose and compare the actual shapes before adopting
this remedy; do not enlarge import tolerances to conceal an unexplained failure.
See the [lower distribution packet](../../../cad/003_FullTank/packets/P01-engine-lower-distribution.md).

For spherical pockets between two parallel trimming planes, the sphere's
parametrization can affect STEP transfer even though rotating a complete sphere
does not change its material. On the same runtime, pockets crossing the default
sphere poles produced valid native cages but invalid STEP solids. Aligning the
sphere axis with the trimming-plane normal made the boundaries latitude circles;
both tested sizes then reopened with zero material differences, in definition
and installed coordinates. Retain the intended spherical geometry and verify
the actual round trip. See the
[isolated pocket export probe](../../../cad/003_FullTank/experiments/drive_chains/engine_crankshaft_build/diagnostics/cage_step_probe/).
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

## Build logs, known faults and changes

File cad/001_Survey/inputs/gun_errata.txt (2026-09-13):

Q. F. HOTCHKISS 2.244-INCH, 6-PDR., 6-CWT. MARK II GUN WITH TANK MOUNTING
Errata and unresolved source readings

Companion to 1919-08-15_Handbook_QF_Hotchkiss_2.244in_6pdr.pdf.
References use printed page/plate numbers. These readings are preserved;
possible corrections have not been established as authoritative.

1. p. 12, spare parts: "2 brushes, sponge" carries an apparent reference E.
   The project flags E as a possible original reference-letter error.

2. p. 12: "2 wrenches, screw driver, for sights (D)" also carries reference E.
   Both the parenthetical D and the separate E are retained; their relationship
   needs editorial comparison rather than an assumed letter substitution.

3. p. 19: "clamp screw brushes" is printed in the source. "Bushes" may have
   been intended, but has not been substituted.

4. Plates II and V: available only in the supplementary, lower-resolution
   scan. Residual bleed-through and limited detail can obscure fine lines or
   labels; no uncertain technical detail has been reconstructed.

Basis: Hotchkiss_Project/data/editorial_notes.json and Hotchkiss_Project/README.md.
Repository revision ae98934e79a3.

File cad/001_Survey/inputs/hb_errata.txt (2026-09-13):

PRELIMINARY HANDBOOK OF THE MARK VIII TANK
November 15, 1918; reprinted March 6, 1925
Errata and unresolved source readings

One companion file for Preliminary_Handbook_MarkVIII_Tank_Part_1_of_5.pdf
through Preliminary_Handbook_MarkVIII_Tank_Part_5_of_5.pdf.
ALL references below are the handbook's original printed page numbers.

The reconstruction preserves the recorded readings, including apparent source
errors. Proposed interpretations are provisional. Repeated codes, quantities
and dimensions have not been silently reconciled. This is a digest of specific
issues already flagged in the project, not a fresh technical certification.

DIMENSIONS, SPECIFICATIONS AND TECHNICAL DESCRIPTIONS

1. p. 9: ground pressure is printed "975 tons per square foot" with no visible
   decimal before 975. No corrected value is established.

2. p. 32: "5-inch flexible brass tubes (Titeflex)" is the visible reading;
   a missing fractional mark has not been assumed. Similar unexplained plain
   "5" dimensions appear in four petrol-system descriptions on p. 213.

3. p. 45: brake horsepower says only "At 1,400 r. p. m." with no power value.
   p. 9 separately gives 338. The same page says each camshaft has 24 cams
   and is driven by bevel gears "from the cam shaft"; both apparent technical
   errors remain. The footnote cautions that much data concerns the airplane
   engine and was taken from a Signal Corps book.

4. pp. 46, 78, 105, 113: inlet tappet clearance differs. p. 46 prints
   0.014-0.16; Plate 50 on p. 78 and the p. 113 summary give .013-.016;
   p. 105 gives .014-.016. The missing zero/apparent lower-limit disagreement
   has not been harmonized.

5. p. 72: grade capability is explicitly "50 degrees - degrees not per cent"
   and "grades of 50 degrees uphill and down." The degree value is preserved.

6. p. 80: bush dimensions use "0.875-0.0005" and "1.125-0.0005." The source's
   hyphens have not been interpreted as a different tolerance convention.

7. p. 104: "Remove the spark plug from the flywheel of No. 6 L cylinder."
   The unusual flywheel reference remains unresolved.

8. p. 115: both asbestos and leather clutch facings are mentioned; the notes
   do not establish whether these describe variants or a source inconsistency.

9. p. 136: road-track driving-wheel diameter is "23.031" without a unit.
   p. 130 gives 39.237 inches outside and 32.75 inside for that wheel, while
   23.031 inches is the chain-sprocket diameter on pp. 130 and 132. The p. 136
   label/value combination is retained, not treated as a reconciled dimension.

10. p. 169: a battery instruction ends "having a specific gravity" without
    giving the value. Different 15/16-ampere limits also remain as printed.

11. pp. 171, 180: ammunition loads differ: 182 common + 26 smoke and 21,000
    machine-gun rounds on p. 171; 184 Q.F. + 24 case-shot and 13,200 machine-gun
    rounds on p. 180. The latter is part of a tentative equipment list approved
    March 7, 1918; do not assume all entries describe one finalized load.

12. pp. 172, 175, 182: machine-gun counts/locations are not reconciled. p. 175
    says seven total, five in the main turret, then lists one front, one rear,
    and two on each side, plus one in each hull side door. That enumeration
    does not agree with the stated five/seven counts.

13. p. 176: ventilation table prints "0.900 cubic feet" at 1,400 r.p.m.; prose
    gives 900 cubic feet per minute at "1.400 r.p.m." Decimal punctuation and
    the incomplete table unit remain unchanged.

14. p. 177: "26-pounder Q. F. Hotchkiss 23-caliber" runs together the quantity
    2 and the 6-pounder designation. It should not be read as a 26-pounder gun.

15. pp. 191, 194, 196, 198: the project flags unusual hardware descriptions:
    p. 191 cover-stud nut 3/4 inch and screw 3/4 inch-16; p. 194 gear bolt
    11/16 inch with 1 5/8 inches between head and nut; p. 196 "stud nut" and
    p. 198 "drain tube bolt nut" each with a 1/16-by-1/2-inch description.
    These remain source readings, not validated fastener specifications.

16. p. 200: the short stud is printed 2 7/10 inches, with a separate
    parenthetical 1 7/16-inch dimension. The unusual denominator 10 was checked
    against the scan and must not be silently changed to 16.

17. p. 203: piston 13149 is described as "20.5 per cent low compression."
    The meaning of this percentage has not been resolved.

18. p. 229, M-2848: "Ball bearing 40 m. m.; bore, 110 m. m.; O. D., 27 m. m
    wide." The sequence attaches dimensions/labels ambiguously; no reordering
    into a presumed bearing specification has been applied.

PART NUMBERS, QUANTITIES AND LEGENDS

19. pp. 86-87: nut lock 8636 versus 8536, and strainer 8220 versus 8230.
    p. 109 uses 8345 for both gasket and bearing retainer.

20. p. 111, Plate 67 ref. 5: the legend reads SH-198B; the drawing reads
    SH193B. Both are preserved.

21. pp. 122, 125: legend ref. 14 is "Striking stud" on p. 122 and "Striking
    rod" on p. 125. p. 125 repeats ref. 18, both times M-255. p. 140 assigns
    M-1472 to both refs. 3 and 7. p. 162 assigns ref. 15 to both Pinion flange
    and Clutch plate.

22. pp. 131, 133, 139: 20297-D89 becomes 2097-D89 on p. 139; no digit added.
    p. 137 ref. 3 prints 1264 without the M prefix.

23. p. 184: distinct O-38-21192 and Q-38-21192 identifiers are retained.
    M-3015 has the unusual paired quantities (L.H.) 2 and (R.H.) 1.

24. Repeated or anomalous nomenclature identifiers remain as printed:
    p. 205 two identical 990C / 1 / Starter spring rows; p. 207 duplicate
    M-335; p. 209 repeated SH158D and SH403B; p. 213 repeated SH980C,
    982F/G/H without SH, and SH894E amid SH984-series entries; p. 215 repeated
    M-1756 and M-1766, with M-3789 before M-3788; p. 225 G-20793 for both a
    rifle-clip spring and long set screw, plus repeated M-2735; p. 227 M-2437,
    two M-2626 rows, a second M-2791, and M-3812; p. 235 repeated M-3311.

25. pp. 223, 233, 235: differing revolver-hole quantities (11, 10, 12, 24),
    and differing inlet/outlet louver-blade and distance-piece quantities,
    remain unreconciled. p. 231 K2-20793 has one quantity, 5, covering two
    description lines for 4-inch and 8-inch chain lengths.

26. Missing fields/numbering are intentional transcriptions of source gaps:
    p. 39 Peephole ref. 3 has no part number; p. 122 omits refs. 19, 45, 51,
    65; p. 156 omits ref. 5; p. 157 omits ref. 11. The nomenclature has
    unnumbered hardware and numbering gaps, including those on pp. 217,
    219 and 221. p. 223 M-2188 has neither description nor quantity.
    Quantities remain blank for 13443 (p. 199), SH981H (p. 211), SH982E and
    SH985F (p. 213), M-3117 (p. 231), and M-858/M-874 (p. 233). p. 235's
    drain cock has no part number. Printed x quantities are not blanks or 1s.

27. p. 239: P-30 has quantity 1 and description "5 Casing"; the unexplained
    5 is retained. The mileage equipment description prints "26 DLh" and
    "revs. to register 1 meter" without editorial normalization.

CROSS-REFERENCES, CAPTIONS AND INDEX

28. p. 7 groups Plate 107, "Third brush regulation," under Chapter X despite
    its electrical subject. p. 20 captions Plate 11 "EPICUCLIC CUP," whereas
    the plate list says "Epicyclic cup." p. 99 captions Plate 65 "FAN BEVEL
    GEAR DRIVE" amid water-pump discussion.

29. Unresolved references include "see fig. 16" (p. 69), "Figure 33" (p. 79),
    "Referring to page -" with no number (p. 120), and Figure 165 / Diagram
    164 / blue print 164 (pp. 167-168). p. 110 points to p. 111 although the
    numbered sectional view is on p. 112.

30. p. 54 has no visible printed Plate 38 label; p. 212's curves have no
    printed Plate 126 label between Plates 125 and 127. None was invented.

31. Index gaps: "Brake, track" (p. 242) and "Engine-oil specifications"
    (p. 244) lack page references. p. 246 has four "Inspection, disassembling
    and" entries, references 70/86/91/99, without subjects to distinguish them.

32. Index conflicts/repetitions: "Fittings and equipment, miscellaneous"
    refers to 177 (p. 245), but its reversed entry to 176 (p. 246).
    "Progress of drive" refers to 13 (p. 247), versus 120 under "Drive,
    progress of" (p. 244). Repeated entries are also retained for Crank shaft
    (94/101), machine-gun locations (175/182), road-track adjusting wheel
    (138/23), driving wheel (23/133/137), upper rollers (19/18), Steering
    (15/148), and removal of roller pinion (135/144). Multiple references
    can describe different discussions; they are not all established errors.

33. Retained wording that can affect interpretation includes "which measures
    with the track links" (p. 14), "cardan shift" (p. 15), "lock hand"
    (p. 42), cables "sent sharply" (p. 67), "new brushed" (p. 70),
    "felt-packing washing" (p. 79), "soft plate" / "Inspect it from the shaft"
    (p. 80), "lack screw holes" (p. 81), "unit No. 8151" after "nuts" (p. 83),
    "tope tweed packing" (p. 100), "tapped clearance" (p. 106), "track
    adjusting steel" (p. 136), "clutch face rises enormously" (p. 164),
    "sear brushes" (p. 170), "taped and threaded" (p. 183), "Ball-crank"
    (p. 188), "adjusting eye belt" (p. 190), "oil hold plug" (p. 196),
    "Dodent plunger" / "Locking belt for pin" (p. 207), and "Operating belt"
    / "Poaking piece" (p. 223). Intended replacements have not been asserted.
    The source also has lesser spelling/punctuation anomalies; their full
    record remains in the project review notes.

Basis: Handbook_Project/REVIEW_NOTES.md, associated BATCH*_NOTES.md and final
index review; cross-checked against the five current PDFs. Repository revision
ae98934e79a3. The existing source/project files remain the detailed audit trail.

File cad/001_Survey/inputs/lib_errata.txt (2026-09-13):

THE 12 CYLINDER LIBERTY AERO ENGINE (SEPTEMBER 1918)
Errata and unresolved source readings

Companion to 1918-09_12_Cylinder_Liberty_Aero_Engine.pdf.
Page references are the manual's printed page numbers, not PDF page numbers.
The reconstruction preserves these readings. Suggested interpretations below
are provisional; this is not a corrected engineering specification.

1. p. 7, illustration index: Fig. 65 (early-pattern cam-spindle drive) is
   referenced to p. 88, although the illustration is on p. 78.

2. p. 9, specific power: 424 h.p. per cubic foot is paired with 15.0 h.p. per
   cubic metre; 247 h.p. per square foot is paired with 2.666 h.p. per square
   metre. The printed imperial/metric pairs do not agree as conversions.

3. p. 10, specifications: exhaust-manifold, starting-gear, fuel/oil-rate and
   six-hour-weight fields are blank. The omitted values have not been supplied.

4. p. 31: the lubrication reference says Figs. 24-29, although the subsequent
   sectioned views also include Fig. 30.

5. pp. 44, 46, Zenith carburettor: p. 46 calls the dipping tube M and the
   compensators I; Fig. 38's legend on p. 44 identifies the dipping tube as L,
   the compensator jet as E, and the shroud tube as I. The conflicting keys
   remain unresolved. The L legend also lacks its closing parenthesis.

6. p. 52: "top of the slow-running position" is the printed wording in the
   throttle-barrel description; the project flags it as a possible wording
   error. No replacement term has been established.

7. pp. 96, 105-106: "be drawn off by either of two methods, viz.:" is misplaced
   at the bottom of p. 96, interrupting the throttle instruction continued on
   p. 97. It appears to complete "The hub may now" on p. 105 before the two
   removal methods on p. 106. That placement is an editorial inference; the
   line remains at its original printed location.

8. pp. 9, 120, 122, 128, 131: the original publication itself revises exhaust
   opening from 50 to 48 degrees before B.D.C., closing from 10 to 8 degrees
   after T.D.C., and nominal tappet clearance from .020 to .019 inch. Older
   values remain in tables, diagrams and prose alongside the printed updates.

9. p. 125: the timing procedure jumps from item 6 to item 8. No missing item 7
   has been reconstructed. p. 128 retains an unexpected reference to p. 86.

10. p. 126: the tappet-setting example mixes R6 and R1. It starts by setting
    R6 clearances while observing R1, then describes R6 valve events and R.1's
    firing point. The intended cylinder sequence has not been established.
    The same page repeats "lower" in "upper and lower / lower inclined shafts."

11. pp. 130-132: the troubleshooting list repeats "Valves" at (v) and (vii)
    and restarts (iii) at "Incorrect jets." Numbering is retained.

12. p. 140, gudgeon-pin fit in rod: the maximum is printed "00125" without
    a decimal point; p. 114 gives .00125 inch. The missing point is retained
    in the reconstructed table.

13. pp. 110, 112, 115 versus pp. 140-141, fits and clearances:
    - Forked-rod end play: .010-.020 inch on p. 115; .008-.020 on p. 140.
    - Camshaft: p. 110 gives rear-bearing end play .001-.003 inch and total
      end play not exceeding .008; p. 140 gives .000-.004, desired minimum
      .002. The scope and differing limits have not been reconciled.
    - Rocker diametrical clearance: .001-.0015 inch on p. 110; .00025-.00175
      on p. 141, desired minimum .001.
    - Oil-pump gear end play: not over .003 inch on p. 112; .002-.007 on
      p. 141, with .003 the desired selection.
    The appendix also separately lists water-pump shaft and bevel-driver
    fits; its values should not be silently substituted into p. 112's prose.

14. Retained apparent printing/worn-letter errors include "interefered"
    (p. 64), "so at to permit of" (p. 65), "pange." after crankshaft (p. 117),
    "Nc. 6" and "bock." (p. 126), "compressicn" (p. 132), "must nct"
    (p. 133), "pump fcr those" (p. 135), "lccking" (p. 136), and "lubricatcr"
    / "attach-attachment" (p. 139). These are documented source readings,
    not new OCR substitutions; see the review notes for minor punctuation.

Basis: Liberty_Project/REVIEW_NOTES.md and retained-source-anomaly entries in
Liberty_Project/data/batch04_corrections.json through batch08_corrections.json;
cross-checked against the current PDF. Repository revision ae98934e79a3.

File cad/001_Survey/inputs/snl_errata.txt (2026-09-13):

STANDARD NOMENCLATURE LIST G-13 - MARK VIII (LIBERTY) TANK
March 30, 1928
Errata and unresolved source readings

Companion to 1928-03-30_SNL_G13_MarkVIII_Liberty.pdf.
References use original printed folios, not electronic PDF page numbers.
The reconstruction retains the source readings. Conflicts and tentative
readings below are not authoritative corrections or engineering specifications.
Apparent quantity mismatches may need further interpretation of component uses.

CONFLICTING IDENTIFIERS, DESCRIPTIONS AND DIMENSIONS

1. pp. 44, 110: plain tachometer-drive-shaft bushing is D22920 on p. 44,
   D29920 on p. 110. The flanged companion D22921 is separately corroborated.

2. pp. 46, 249: the left distributor-to-left No. 3 spark-plug cable lists
   spark-plug terminal LQ328A on p. 46. p. 249 distinguishes distributor-end
   LQ328A from spark-plug-end LQ329A. p. 249 also has anomalous cable references
   LQ328A and SH102L that differ from related cable-code forms.

3. pp. 45, 52: left engine-room festoon-lamp cable is 2 ft versus 8 1/2 ft;
   left distributor cable is 12 1/2 ft versus 12 ft in the respective lists.

4. pp. 58, 59, 105, 237: stud LQ196A is 1 9/16 inches on pp. 58, 105, 237,
   but 1 3/16 on p. 59. Note (ge) concerns oversize replacement LQ484A and
   does not resolve two lengths for LQ196A.

5. pp. 67, 79: p. 67 calls LQ296A the lower valve-spring collar and LQ297A
   the upper; p. 79 reverses those descriptions. Orientation is unresolved.

6. pp. 87, 88, 90 versus p. 309: engine headings read "Trego," while the
   later note says "Treco Motor Co." Both source forms remain.

7. p. 115, battery-to-telephone-switch-panel lead: assembly length 24 inches
   and quantity (4), but component cable length 41 inches and quantity (1).

8. pp. 138, 219, SH642B Belleville spring: inside diameter 13/16 inch on
   both pages; outside diameter 1 1/2 inches on p. 138, 1/2 inch on p. 219;
   both appear to say 1 inch thick. The p. 219 outside diameter is smaller
   than its inside diameter. Note (gh) does not resolve the dimensions.

9. pp. 146, 165: piston ring LQ469A is "bottom" in the assembly, "top" in
   its individual entry. Notes (gw)/(gaj) distinguish old/replacement pistons
   but do not settle the ring position.

10. pp. 140-141: D29864 appears as both nut and screw. p. 145 repeats the
    SH169K 3/4-by-12 1/2-inch pipe row twice, each quantity 1 and price .12 P.

11. pp. 223-224: the same platform ammunition-storage assembly has
    identification 18 on p. 223 and 48 on p. 224.

12. pp. 237-238: LQ229A thread length is 1 15/16 inches on p. 237 and
    1 5/16 on p. 238; identification changes from 13154 to 1354. p. 59
    corroborates 1 15/16. The continuation's conflicting values remain.

13. p. 240: LQ166A washer is given as 5/8 inch and MX25 stud assembly uses
    a castle nut described as S.A.E. 1 inch; the project flags conflicts with
    related dimensions without establishing replacements.

14. pp. 274-275: M1405X track-wheel diaphragm has drawing reference 58 on
    p. 274 and 59 on p. 275.

APPARENT QUANTITY DISAGREEMENTS AND AMBIGUOUS NOTATION

15. p. 29: 3/8-by-3/4-inch hexagon bolt quantity 49, but the listed uses
    are rest 5X90 (2) and plate M1033 (9).

16. pp. 82-83: M708 side-door clip component counts differ: left "one,"
    right "two (4)." p. 120 gives left door-lock assembly (4), right (2),
    but bracket/packing-piece components (4) for both.

17. p. 139: A8035 rod-end-pin assembly (4), component (2). pp. 150-152:
    revolver-hole cover quantity 7 versus parenthetical total 5.

18. p. 166: 3/16-by-5/8-inch rivet quantity 273 versus listed uses totaling
    21. Further unreconciled totals flagged by the project: 3/4-by-2 1/8-inch
    rivet 203 (p. 189), first countersunk rivet 1,082 (p. 191), and
    1/4-by-1/2-inch round-head screw 49 (p. 201).

19. pp. 191, 225: platform rivets are 386 on p. 191 and 388 in the p. 225
    component list. p. 211 prints "two LQ65G tube END, short (3)."

20. Quantity notation differs from neighboring entries: M568C assembly 44
    without parentheses (p. 136), piston assembly 12 without parentheses
    (p. 146), and starred M1401 driving-wheel rim 4 without parentheses
    (p. 164). These forms have not been silently regularized.

21. Blank quantities, prices and identifiers remain blank, including the
    two clip quantities on p. 66; telephone fuze fields on p. 97; LQ430A
    quantity on p. 129; M1949 Ordnance cell on p. 146; LQ299A spark-plug
    quantity on p. 156; A6951 chain-ring quantity on p. 165; M1904C quantity
    on p. 230; and clutch-throwout quantity on p. 250. No omitted count is
    inferred from analogous assemblies. review.json lists the other blanks.

UNCERTAIN OR ANOMALOUS CODES AND REFERENCES

22. p. 20: lock-wire code reads "-Q512B" with an unclear/missing initial L.
    Related codes suggest LQ512B, but p. 276 does not repeat its full mark.
    p. 93 strap-fastener code looks like NBIB; NB1B is clear on pp. 107, 223.
    Those cross-references support likely identities, not the disputed glyphs.

23. pp. 48, 149: manufacturer numbers L12339 and L3308, and louver plate
    mark 995B without M, remain as printed despite neighboring patterns.
    p. 237's apparent LA88A contrasts with LQ88A elsewhere and in note (ge).

24. Unresolved rivet-use code variants include:
    p. 167 M3790B versus related M3780B; p. 168 M2373 for both plate/batten;
    p. 172 tentative M6412; p. 173 M308B9, M2102A/B, SH492B;
    p. 174 M2056 without A and M2073A/B; pp. 175-176 beam 1927, angle 2318B,
    bracket M2036 and alternating angle/plate names; p. 177 repeated M1976B
    in left/right combinations; p. 178 M2794A/M2784B among M379x references;
    p. 179 plate M2077; p. 183 M2768A opposite M2786B;
    p. 184 repeated M2017B; p. 185 M2017 without suffix and M2073;
    p. 187 repeated M2007A, bracket M3922 and plate M2733;
    p. 188 M2422 for both batten/strap; p. 190 M3818 and M2000B versus
    M3918/M2008A elsewhere; p. 201 reversed-form "2010M B."
    These are flagged source forms, not a proposed mass renumbering.

25. p. 186: adjacent plate M1977 / angle M2106A and angle M1972A / plate
    M1977 references lack intervening punctuation/quantity. None supplied.

26. Further uncertain codes: SH81H (p. 203, faint H); 8X00 (p. 216, numeric
    first character); SS577B/D/C/E (p. 223, versus SH-prefixed listings);
    L8460 for LQ461A (p. 258); D30365 in D20495 washer references (p. 269,
    blurred final digits); D39536 distributor-cup stud (p. 272).

27. p. 165, A6951: note (a) has no standalone definition in pp. 307-311.
    Note (d) on p. 308 discusses the relevant chain-ring/S-hook replacement
    and is a possible intended reference, not an established correction.

28. p. 261, LQ186A: plate reference reads 141, although the book has only
    34 plates. Plate 14 is plausible but not established. p. 264:
    identification 2 / plate 10 beside the M2370B outlook-turret angle rows
    has uncertain row attachment; the reconstruction follows the rear row.

29. Screw-diameter marks on pp. 112, 119, 205-207 include small plus/minus
    signs beside fractions; their placement is not a modern tolerance
    interpretation. The unusual D26948 thread No. 6-38 on pp. 204, 244 was
    confirmed as printed; that confirms the reading, not the physical thread.
    p. 131's packing length 11 9/16 inches still needs independent checking.
    p. 273 associates a 1-inch plain washer with a 1/4-inch bolt.

PRICES AND WORDING

30. Uncertain prices: M2007/2008 A/B 22.60 (p. 3); M2027 A/B 3.98 (p. 6);
    M1900 8.98 (p. 15); camp-kettle bracket 2.99, possibly 2.98 (p. 37);
    M2848/478 sponson-door roller 1.58, possibly 1.53 (p. 197); removable
    platform assembly 41.68 (p. 225); M367 brake strap 8.20, possibly 3.20
    (p. 229); M3292 oil-tank body 26.60 (p. 245). These are retained readings,
    not independently verified price corrections.

31. Price notation/placement: pyrene-refill bracket ".672 P" (p. 40) is
    anomalous but source-checked; .25 aligns with a stove-bolt row rather
    than connector (p. 70); a mark before M2389's 22.78 is unresolved and
    omitted from the numeric cell (p. 147); 11/16-by-3 1/4-inch rivet .02 P
    is anomalous relative to nearby prices (p. 189); 6.93 aligns with two
    SH958E coupling nuts above the SH958A spindle (p. 219).

32. Apparent source wording includes ANFLE (p. 3, possibly damaged G), two
    OLT headings (p. 32), "lower crack case sump" (p. 76), "large plant
    pinion" (p. 80), "scoup" spring (pp. 134, 219, corroborated literally),
    "engine oiled tank" (p. 156), SEPARTATOR (p. 158), "rear shall storage"
    (p. 223), generator brush "and" rather than "arm" (p. 234), "cam shaft
    locker lever" (p. 248), "ball bearieg WASHER" (p. 250), "distributing
    left" (p. 260), and "stove volt" (p. 268). No technical term was silently
    substituted; lesser punctuation issues remain in the detailed review.

33. Plate 2, marked "Face p. 277," is placed after p. 277 for reading order.
    Its original binding placement and foldout dimensions are unconfirmed.
    Corrected plate images retain uncertainty in original aspect ratio and
    interior geometry; their displayed scale is not an independent dimension.

The latest audit corrected SH40A1D to SH40AD (p. 61), SH976C clip identity
(p. 66), and the first transmission-frame rivet length to 1 1/8 inches
(p. 97). Those transcription errors are already resolved. Repeated SH599A
manifold components were explained by note (go), not treated as an error;
606 radiator tubes and generator-washer identification 8209 were corroborated.

Basis: SNL_G13_Project/review.json, SNL_G13_Project/TRANSCRIPTION_AUDIT.md and
SNL_G13_Project/audit/ambiguity_audit.json; latest dispositions take precedence
over old checkpoint flags. Repository revision ae98934e79a3.

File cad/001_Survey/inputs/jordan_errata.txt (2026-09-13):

MANUFACTURE OF MARK VIII TANKS AT ROCK ISLAND ARSENAL - HARRY B. JORDAN
Errata and ambiguities

Companion to 1920-07_Manufacture_of_Mark_VIII_Tanks.pdf.
References are original article pages 27-33. Source readings remain unchanged.

1. p. 32, duration: July 1, 1919 to June 5, 1920 is stated as 286 days.
   The elapsed calendar interval is 340 days. The article does not establish
   a counting convention that resolves the discrepancy.

2. p. 32, production rate: January 5 to June 5, 1920 is described as 150 days
   and an average of one tank every 36 hours on a 24-hour-day basis. The actual
   elapsed interval is 152 days; 36 hours follows from the article's rounded
   150-day figure and 100 tanks. Treat it as Jordan's stated average.

3. pp. 28, 32-33: p. 32 dates the last tank's completion/readiness for road
   test to June 5; pp. 28 and 33 give June 10 for last completion. The June 14
   congratulatory letter reproduced on p. 27 also says assembly was completed
   on June 10. These may reflect different milestones, but the terminology
   does not fully resolve the difference. June 15 is the promised deadline.

4. p. 29: "The man and officer's turrets" is printed as "man," not "main."
   The rivet dimension is printed "11-16 inch"; the reconstruction retains
   that notation rather than silently changing it to 11/16.

5. p. 30: heading "Product of Components" is retained; p. 31 separately uses
   "Manufacture of Components." p. 32 prints "semaphone" in the accident
   account, rather than "semaphore."

6. Added cover: its source is a bound-volume title page for Volume I,
   July-August 1920 through May-June 1921, not the July-August issue cover.
   The article belongs to No. 1, July-August 1920. Article identification and
   citation on the reconstructed cover are modern editorial additions.

Basis: Article_Project/REVIEW_NOTES.md and Article_Project/TRANSCRIPTION.md;
calendar intervals checked independently. Repository revision ae98934e79a3.

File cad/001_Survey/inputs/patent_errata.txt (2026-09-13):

U.S. PATENT 1,366,550 - TANK (HERBERT W. ALDEN)
Source-wording note

Companion to US1366550A_cleanup.pdf.

Specification, first text page, left column, introductory paragraph:
"ultimate perfection of the gun as an entirety" is the original wording,
although the surrounding discussion concerns the tank and its pivoting
sponson. The reconstruction retains "gun"; no replacement word is established.

The project records no other unresolved textual contradiction. Its chamber
13/18 and wall 3/8 questions were resolved as scan/OCR confusions during source
review and are not outstanding errata.

Basis: US1366550A_Project/README.md and
US1366550A_Project/data/transcription_lines.txt. Repository revision ae98934e79a3.

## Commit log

2026-09-12 Add Initial GPT-6 Astra Scribus transcription of Mark VIII SNL G13 manual
    [page_inventory.tsv]
2026-09-13 Add GPT 6 Scribus conversion of the Preliminary Handbook scans.
    [batch10_table_transcription.tsv, batch11_table_transcription.tsv, batch12_index_transcription.tsv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]
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2026-09-13 Add GPT 6 produced Scribus version of Hotchkiss 6pdr manual
    [page_inventory.csv]
2026-09-13 Add GPT 6 Scribus transcription of Manufacturing article.
    [p27_L.tsv, p27_Ltop.tsv, p27_R.tsv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]
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2026-09-20 Record installed pinion checks and drive-chain source conflicts
    [Alternative37Teeth.FCStd, FuelBackplateCandidate.FCStd]
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2026-09-20 Document chain phase closure and source-sized roller clearance failures
    [candidate.FCStd, current.FCStd]
2026-09-20 Preserve recovered chain fixtures and document restart recovery
    [DriveChainCandidate.FCStd, InstalledChainsCandidate.FCStd, flanks_15.FCStd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]
2026-09-20 Test inferred chain-casing passages against the installed hull
    [CasingPassageCandidate.FCStd]
2026-09-20 Save validated milestone 010 and native chain-casing fit candidates
    [CasingPassageCandidate.FCStd, CasingShellCandidate.FCStd, CasingWallMountCandidate.FCStd]
2026-09-20 Add and qualify isolated casing cap cleats and fasteners
    [CasingCapCandidate.FCStd]
2026-09-20 Fit casing registers, beading and supports with source-correct packing
    [CasingCapCandidate.FCStd, CasingSupportCandidate.FCStd, CasingTrimCandidate.FCStd]
2026-09-20 Preserve recovered chain retention and oil-passage detail study
    [ChainDetailCandidate.FCStd]
2026-09-20 Add transmission output rotors and qualify casing clearance and pinion integration
    [CasingFrontCandidate.FCStd, TransmissionOutputCandidate.FCStd]
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2026-09-20 Add source-bound output sleeves, dowels and retaining rings
    [TransmissionBushCandidate.FCStd]
2026-09-20 Model fixed transmission bearings and expose frame-case interference
    [FixedBearingParts.step, TransmissionSupportCandidate.FCStd]
2026-09-20 Reconstruct transmission frame and document nominal clearance limits
    [FrameAndRevisedBrackets.step, TransmissionFrameCandidate.FCStd]
2026-09-20 Add closed transmission oil-cover hinges and native fit evidence
    [OilCoverHinges.step, TransmissionLidCandidate.FCStd]
2026-09-20 Add transmission cap studs, castle nuts and split-pin fit evidence
    [CapStudsAndReceivers.step, TransmissionStudCandidate.FCStd]
2026-09-20 Populate transmission cap oil fittings, packing and bearing galleries
    [CapLubricationAndPassages.step, TransmissionOilCandidate.FCStd]
2026-09-20 Reconstruct central transmission shells, carriers and cross shaft
    [TransmissionCoreCandidate.FCStd, TransmissionCoreParts.step]
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2026-09-20 Populate large planet pin supports and recessed carrier seats
    [TransmissionPinCandidate.FCStd, TransmissionPinParts.step]
2026-09-21 Correct transmission ring-bolt source station and recessed seats
    [TransmissionRingSupportCandidate.FCStd, TransmissionRingSupportParts.step]
2026-09-21 Populate small planetary gears, bushed sun sleeves and riveted input disks
    [TransmissionSmallCandidate.FCStd, TransmissionSmallParts.step]
2026-09-21 Add small planetary supports and swept riveted input disks
    [TransmissionSmallSupportCandidate.FCStd, TransmissionSmallSupportParts.step]
2026-09-21 Add small-sun retaining rings and mating drum clearances
    [TransmissionSunRetentionCandidate.FCStd, TransmissionSunRetentionParts.step]
2026-09-21 Add bevel sleeve supports and assembly-compatible shaft journals
    [TransmissionBevelSleeveCandidate.FCStd, TransmissionBevelSleeveParts.step]
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2026-09-21 Populate input cover fasteners and grease feed; repair cotter legs
    [TransmissionInputInstallationCandidate.FCStd, TransmissionInputInstallationParts.step]
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2026-09-21 Populate reversing fork, rod and spring detent
    [TransmissionReversingCandidate.FCStd, TransmissionReversingParts.step]
2026-09-21 Populate vertical reversing shaft, levers and bearing attachments
    [TransmissionVerticalCandidate.FCStd, TransmissionVerticalParts.step]
2026-09-21 Preserve checked MX5 mounting trial and source-profile discrepancy
    [MX5CaseMountParts.step, MX5CaseMountTrial.FCStd]
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2026-09-21 Build source-linked air-pressure pump core with checked internal geometry
    [AirPressurePump.FCStd, AirPressurePump.step, AirPressurePumpDefinitions.step]
2026-09-21 Add checked air-pump mounting reconstruction and conditional belt datum
    [AirPumpInstallation.step, AirPumpMountDefinitions.step, TransmissionWithAirPump.FCStd]
2026-09-21 Add clutch-stop coupling and closed air-pump belt drive
    [ClutchDriveDefinitions.step, ClutchDriveInstallation.step, TransmissionWithClutchDrive.FCStd]
2026-09-21 Add front clutch coupling and seated NURBS spring
    [FrontClutchDefinitions.step, FrontClutchInstallation.step, TransmissionWithFrontClutch.FCStd]
2026-09-21 Add clutch collar joint and correct coupling topology
    [ClutchCollarDefinitions.step, ClutchCollarInstallation.step, TransmissionWithClutchCollar.FCStd]
2026-09-21 Populate main clutch bearing sleeve and keyed support
    [ClutchStackDefinitions.step, ClutchStackInstallation.step, TransmissionWithClutchStack.FCStd]
2026-09-21 Benchmark Astra reasoning efforts on bounded CAD reconstruction tasks
    [bearing.step, candidate.FCStd, collar.step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]
2026-09-23 Add isolated CAD work-packet controller and tool-enabled shadow protocol
    [broken_mount.FCStd, fixed.FCStd, fixed.step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]
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2026-09-23 Record tool-enabled CAD trials, reviews and discovered FreeCAD skill
    [fixed.FCStd, fixed.step, nominal.FCStd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]
2026-09-23 Qualify corrected clutch core and preserve source-corrected views
    [ClutchStackDefinitions.step, ClutchStackInstallation.step, TransmissionWithClutchStack.FCStd]
2026-09-23 Reconstruct and qualify clutch thrust balls, retainer and stop ring
    [ClutchThrustDefinitions.step, ClutchThrustInstallation.step, TransmissionWithClutchThrust.FCStd]
2026-09-23 Reconstruct and qualify clutch cone, lining and six spring sets
    Add 71 source-linked occurrences, refine the keyed support, and retain source conflicts and inferred profiles. Validate 462 independent checks, 326 material pairs, native/STEP exchange, coupled varia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
    [ClutchConeDefinitions.step, TransmissionWithClutchCone.FCStd, larger.FCStd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]
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2026-09-23 Reconstruct and qualify clutch drum and engine flywheel
    [ClutchDrumDefinitions.step, ClutchDrumInstallation.step, TransmissionWithClutchDrum.FCStd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]
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2026-09-23 Develop clutch release bearings, forks and main shaft
    [ClutchThrowoutDefinitions.step, ClutchThrowoutInstallation.step]
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2026-09-23 Develop hollow Liberty crankcase castings and verify support clearances
    [EngineCaseDefinitions.step, EngineCaseInstallation.step]
2026-09-23 Develop Liberty crankshaft and bearing installation with verified clearances
    [5.8_X_definition.step, 5.8_X_installed.step, 5.8_Z_definition.step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]
2026-09-23 Populate Liberty crankshaft closures and validate oil passages
    [EngineShaftFittingsDefinitions.step, EngineShaftFittingsInstallation.step]
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2026-09-23 Model lower-drive receiving casting and verify pump openings
    Revise the integral lower crankcase to receive the existing lower driver,
    support its retaining screw, and provide oil access and pump mounting openings.
    Preserve the other 2,169 occurrences and retain estimated dimensions explicitly.
    Pass 25 native checks, 261 affected material pairs, two strict STEP comparisons,
    actual gear mesh/backlash, a seven-control trial, and a fresh geometry/hierarchy
    reproduction. Save six reviewed views and two progression snapshots. Document
    the reproduced FreeCAD cleanup tolerance regression in the reconstruction skill.
    Complete pump fit, remaining engine systems and standard integration are pending.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
    [LowerCaseDefinition.step, LowerCaseInstallation.step, before_cleanup.step]
2026-09-23 Add water-pump development assembly and retain unresolved casting checks
    Populate 60 pump constituents in 24 definitions, including the geared shaft,
    bearing internals, packing/glands/spring, open impeller, castings and cover hardware.
    Preserve the 2,170 parent occurrences and save two visual progression images.
    All 26 native checks and 202 material comparisons pass. STEP passes 82 of 84
    comparisons: the body exceeds the existing native kernel-tolerance limit in both
    frames, despite valid exports and zero material differences. Preserve diagnostics
    and failed trials; this is an unqualified development checkpoint.
    Record the tested cage sphere-parametrization repair in the FreeCAD skill.
    Pri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
    [WaterPumpDefinitions.step, WaterPumpInstallation.step, radial_poles.step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]
2026-09-23 Develop water-pump mounting and verify the nominal casting
    Add four source-length mounting stud sets and integral receiving pads, reconcile
    the flange stack, and revise tangential outlets and the flat drain seat. The
    2246-occurrence development model passes38 native checks,472 affected material
    pairs,106 strict STEP comparisons and exact fresh nominal reproduction.
    Preserve the failed six-control trial: the drain boss intrudes into an outlet
    passage gauge at the altered angle. The coupling correction, drain lock wire,
    source conflicts and full-engine/standard integration remain open. Retain two
    progression images and the tested empty-compound FreeCAD skill lesson.
    [LowerCaseDefinition.step, LowerCaseInstallation.step, WaterPumpDefinitions.step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]
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2026-09-24 Record high-speed brake support evidence and fixed-view receiver study
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2026-09-24 Add retained rear-control fulcrums with fixed-camera evidence
    [RearControlFulcrums.FCStd, RearControlFulcrumsDefinitions.step, RearControlFulcrumsInstalled.step]
2026-09-24 Preserve rear spring-guide trials and correct short brake connections
    [RearHighSpringBrackets.FCStd, RearHighSpringBracketsDefinitions.step, RearHighSpringBracketsInstalled.step]
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2026-09-27 Rebuild center foot controls with source-correct pivots and checked floor joints
    [ControlRebuildTrial.FCStd, RebuiltControlAdditionsDefinitions.step, RebuiltControlAdditionsInstalled.step]
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2026-09-27 Rebuild complete rear high controls with physical spring seats and corrected floor mounts
    [ControlRebuildTrial.FCStd, RebuiltControlAdditionsDefinitions.step, RebuiltControlAdditionsInstalled.step]
2026-09-27 Rebuild complete low-speed and center-foot rods with physical joints and shared receiver clearance
    [ControlRebuildTrial.FCStd, RebuiltControlAdditionsDefinitions.step, RebuiltControlAdditionsInstalled.step]
2026-09-27 Complete corrected clutch controls and close withheld control redo
    [ControlRebuildTrial.FCStd, RebuiltControlAdditionsDefinitions.step, RebuiltControlAdditionsInstalled.step]
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2026-09-27 Reconstruct low-speed front receivers and correct overlapping driver link eyes
    [ControlRebuildTrial.FCStd, RebuiltControlAdditionsDefinitions.step, RebuiltControlAdditionsInstalled.step]
2026-09-27 Build low-speed selectors and correct diagonal M762 connections
    [ControlRebuildTrial.FCStd, RebuiltControlAdditionsDefinitions.step, RebuiltControlAdditionsInstalled.step]
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2026-09-27 Test full handle profiles and identify reversed front hull rake
    [ControlRebuildTrial.FCStd]
2026-09-27 Build bow and enclosure hypothesis with explicit driver-fit failures
    [BowEnclosureHypothesis.FCStd, BowEnclosureHypothesis.step]
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2026-09-27 Establish seat reconstruction evidence and correct bearing rivet transcription
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2026-09-27 Check central brake pedal group and expose incompatible foot-link profiles
    [ControlRebuildTrial.FCStd, RebuiltControlAdditionsDefinitions.step, RebuiltControlAdditionsInstalled.step]
2026-09-28 Check reverse lever body and complete third short-rod connection
    [ControlRebuildTrial.FCStd, RebuiltControlAdditionsDefinitions.step, RebuiltControlAdditionsInstalled.step]
2026-09-28 Check mounted reverse quadrant with full stock and actual support bores
    [ControlRebuildTrial.FCStd, RebuiltControlAdditionsDefinitions.step, RebuiltControlAdditionsInstalled.step]
2026-09-28 Probe reverse latch routes against saved blade and seat receivers
